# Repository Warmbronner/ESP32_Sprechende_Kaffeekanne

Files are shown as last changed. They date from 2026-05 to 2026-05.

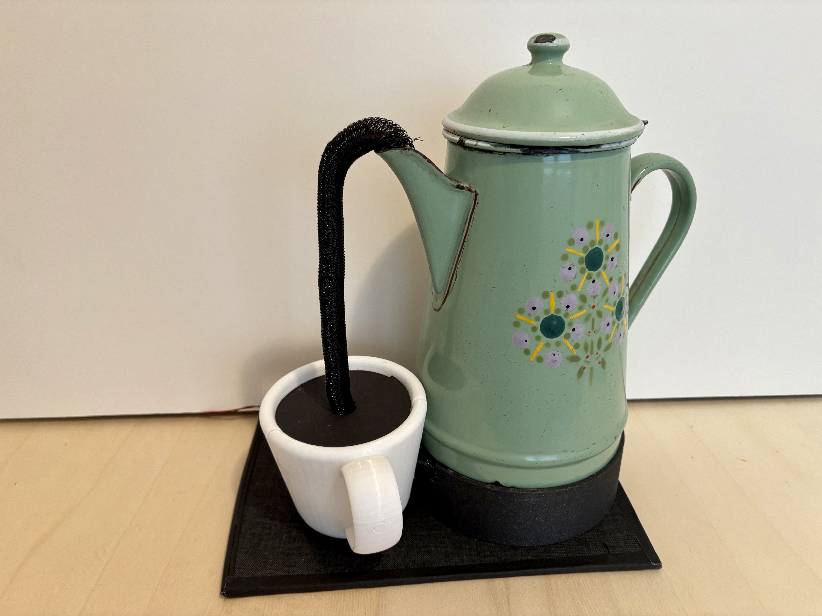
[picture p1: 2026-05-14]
Bilder/Abbildung3.jpeg

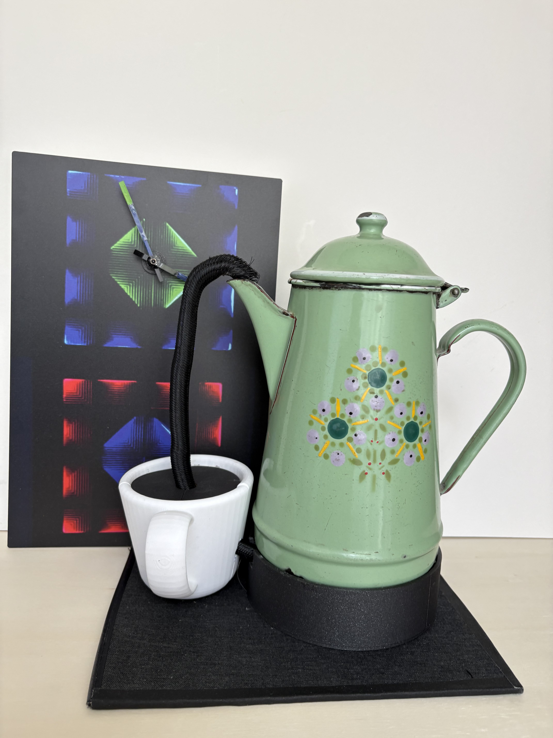
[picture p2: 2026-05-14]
Bilder/Abbildung7.jpeg

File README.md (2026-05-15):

# ESP32_Sprechende_Kaffeekanne
</> Markdown
# Sprechende Kaffeekanne
Sprechende_Kaffeekanne

Historische Kaffeekanne mit ESP32, MP3-Player, Servo und Neo Pixel als sprechende Uhr

Projektbeschreibung:
Eine historische Blech-Kaffeekanne lernt sprechen: Mit ESP32, MP3-Modul, Servo und etwas Fischertechnik entsteht eine ungewöhnliche Uhr mit Charakter.
•	Kombination aus Mechanik, Audio und Licht
•	Modulares Innenleben ohne Veränderungen an der Kanne
•	ESP32 mit WLAN-Zeitabgleich und synchronisierter Bewegung

Funktionen
Hardwareliste
•	ESP32 NodeMCU 32S
•	Servo M90 mit Metallgetriebe
•	MP3 MiniPlayer
•	Lautsprecher 8 Ohm, passend zum MP3 Player
•	Breadboard mini 2 x 3 cm
•	2 Widerstände 670 Ohm
•	1 Kondensator 0,01 F
•	NeoPixel-Streifen mit 4 LED’s
•	Jumperkabel
•	PLA Filament für Drei D Drucker
•	Klettband
>Kabelschlauch
•	3 Neodym Magnete 10 x 3 mm
•	4 Neodym Magnete 3 X 2 mm
•	Kabelbinder 
•	2 Gewindehülsen M3

Benötigte Werkzeuge:
•	3D-Drucker
•	Lötkolben
•	Seitenschneider
•	Heißklebepistole oder Sekundenkleber

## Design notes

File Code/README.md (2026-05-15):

Kaffeekanne_sprechend.ino ist der Code zur Steuerung des Projektes
KaffeeKanne_Test.ino ist der Code zum Testen der Funktionen und zur Abstimmung der Synchronisation MP3-dateien und Bewegung
Abgestimmt aus ESP32 NodeMCU-32S

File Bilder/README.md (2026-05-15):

Die Files, beginnend mit K3... sind für den Kasten 3 des Artikels vorgesehen.
Sollen in kleiner Bildgröße, etwa 3 x 3 cm dargestellt werden

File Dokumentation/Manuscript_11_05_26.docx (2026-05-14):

# Titel

Sprechende Kaffeekanne

# Vorspann

Eine historische Blech-Kaffeekanne lernt sprechen: Mit ESP32, MP3-Modul, Servo und etwas Fischertechnik entsteht eine ungewöhnliche Uhr mit Charakter.

# Kurzinfo

- Kombination aus Mechanik, Audio und Licht
- Modulares Innenleben ohne Veränderungen an der Kanne
- ESP32 mit WLAN-Zeitabgleich und synchronisierter Bewegung

Checkliste

Zeitaufwand: ein Wochenende

Kosten:
ca. 40 bis 60 Euro je nach vorhandenen Materialien und 3D-Druckmöglichkeiten, ohne Fischertechnik

Benötigte Kenntnisse:

- Grundlagen Arduino IDE
- Löten und Verdrahten
- Einfache Konstruktion mit 3D-Druck

Material

- ESP32 NodeMCU 32S
- Servo M90 mit Metallgetriebe
- MP3 MiniPlayer
- Lautsprecher 8 Ohm, passend zum MP3 Player
- Breadboard mini 2 x 3 cm
- 2 Widerstände 670 Ohm
- 1 Kondensator 0,01 F
- NeoPixel-Streifen mit 4 LED’s
- Jumperkabel
- PLA Filament für Drei D Drucker
- Klettband >Kabelschlauch
- 3 Neodym Magnete 10 x 3 mm
- 4 Neodym Magnete 3 X 2 mm
- Kabelbinder
- 2 Gewindehülsen M3

Benötigte Werkzeuge:

- 3D-Drucker
- Lötkolben
- Seitenschneider
- Heißklebepistole oder Sekundenkleber

# Einleitung

Es gibt Projekte, die sind praktisch. Und es gibt Projekte, die machen einfach Spaß – oft mit deutlich höherem Lernfaktor. Dieses hier gehört eindeutig zur zweiten Kategorie.

Auf einer Kommode in unserem Haushalt steht eine rund 100 Jahre alte, emaillierte Blech-Kaffeekanne. Eigentlich ein reines Dekostück – bis sich die Frage aufdrängte: Warum sollte sie nicht mehr können, als nur gut auszusehen?

Die Idee: Die Kanne soll sprechen. Genauer gesagt, sie soll regelmäßig die Uhrzeit ansagen – zur vollen oder halben Stunde. Eine etwas andere „sprechende Uhr“, die garantiert mehr Aufmerksamkeit bekommt als jedes Display.

Der besondere Reiz liegt im Detail: Der Deckel der Kanne ist beweglich und eignet sich perfekt, um als „Mund“ zu fungieren. Synchron zur Sprachausgabe soll er sich öffnen und schließen – eine mechanische Illusion von Sprache.

Von Anfang an war jedoch klar: Die Kanne selbst bleibt unangetastet. Keine Bohrungen, keine Klebespuren, keine bleibenden Veränderungen. Die gesamte Technik muss sich unsichtbar integrieren und rückstandslos wieder entfernen lassen – eine Herausforderung, die das Projekt erst richtig interessant macht.

Bildunterschrift Abbildung 1:
Die emaillierte Kaffeekanne dient als Basis des Projekts. Äußerlich bleibt sie vollständig unverändert.

# Konzept und Lösungsansatz

Damit aus der stummen Kanne ein erzählfreudiges Objekt wird, braucht es im Kern drei Dinge: Bewegung, Ton und ein wenig Inszenierung. Konkret heißt das: Der Deckel muss sich bewegen, eine Sprachausgabe muss abgespielt werden – und als visuelles Extra sorgt ein Licht im Inneren für den passenden „magischen“ Effekt. Gesteuert wird das Ganze von einem Mikrocontroller, der zusätzlich die aktuelle Uhrzeit ermittelt und verarbeitet.

Damit zerfällt das Projekt in vier zentrale Aufgaben:

- Mechanik für die Deckelbewegung
- Audioausgabe
- Beleuchtung
- Zeitbasis inklusive Steuerlogik

# Mechanik

Für die Bewegung des Deckels standen zunächst mehrere Ansätze zur Diskussion. Die erste Idee war ein klassischer Kurbeltrieb mit Pleuelstange. Funktioniert grundsätzlich gut, ist aber mechanisch vergleichsweise aufwendig.

Deutlich pragmatischer erwies sich der zweite Ansatz: Fischertechnik. Davon ist im Haushalt reichlich vorhanden, und die modularen Bauteile eignen sich perfekt für schnelle Prototypen. Der Antrieb erfolgt über einen Servo, da sich damit Positionen exakt anfahren lassen und der Nullpunkt zuverlässig reproduzierbar ist.

Zum Einsatz kam ein Servo M90 mit Metallgetriebe – robust genug für die Aufgabe und gut kontrollierbar. Die Kopplung zwischen Servo und Mechanik entstand aus einer improvisierten, aber effektiven Lösung: einer Scheibe mit Stellschraube, kombiniert mit den originalen Servoarmen. Zwei kleine Holzschrauben sorgen für die kraftschlüssige Verbindung.

Bildunterschrift Abbildung 2:
Die Mechanik kombiniert Fischertechnik-Bauteile mit einem kleinen Servo und einer selbstgebauten Kupplung.

Die Schubstange steht im eingebauten Zustand senkrecht und wird über eine Führung im Deckel stabilisiert. Der Servo selbst sitzt in einem 3D-gedruckten Gehäuse, das auf einem Fischertechnik-Element befestigt beziehungsweise verklebt ist.

# Audio

Für die Sprachausgabe fiel die Wahl schnell auf einen bewährten Klassiker: einen MP3-Mini-Player mit angeschlossenem Lautsprecher. Damit lässt sich die Audiowiedergabe unkompliziert ansteuern.

Aufwendiger als gedacht war hingegen die Erstellung der passenden Sprachdateien. Die Ansage muss nicht nur korrekt sein, sondern auch zeitlich zur Deckelbewegung passen. Erste Versuche mit Smartphone-Aufnahmen erwiesen sich als umständlich, vor allem wegen der nötigen Nachbearbeitung und Konvertierung.

Die Lösung brachte schließlich Audacity: aufnehmen, schneiden, anpassen – alles in einem Werkzeug. Damit ließ sich die Synchronisation zwischen Bewegung und Ton sauber umsetzen.

# Licht

Für den zusätzlichen Effekt sorgt eine dezente Innenbeleuchtung. Hier kommen adressierbare LEDs vom Typ NeoPixel zum Einsatz. Ein kurzer Streifen mit vier LEDs reicht völlig aus – tatsächlich werden nicht einmal alle benötigt.

Während der Sprachausgabe leuchtet das Kanneninnere leicht auf und verstärkt so den Eindruck, dass „innen etwas passiert“.

# Elektronik

Die ursprüngliche Idee war, die komplette Technik in der Kanne zu verstecken. In der Praxis scheiterte das schnell am verfügbaren Platz – und an der Wartbarkeit.

Gerade beim verwendeten ESP32 NodeMCU32S müssen zum Programmieren Taster zugänglich sein. Auch die SD-Karte des MP3-Moduls soll ohne Zerlegen erreichbar bleiben. Zudem lebt das Projekt davon, dass man später Dinge verändern und erweitern kann.

Die Lösung: Ein separater, abnehmbarer Unterbau. Darin sitzen:

- Mikrocontroller
- MP3-Modul
- Stromversorgung

Die Verbindung zur Kanne erfolgt über ein Kabelbündel, das durch die Tülle geführt wird. Optisch verschwindet es in einer schwarzen Ummantelung – getarnt als „Kaffeestrahl“. Der Übergang zum Unterbau wird zusätzlich durch eine dekorativ platzierte Tasse kaschiert.

Bildunterschrift Abbildung 3:
Der Unterbau enthält Elektronik und Stromversorgung. Die Verkabelung verschwindet im „Kaffeestrahl“.

# Innenleben

Das Innere der Kanne ist schwer zugänglich – also musste eine modulare Lösung her. Alle Komponenten im Inneren wurden zu einer kompakten Einheit zusammengefasst, die sich komplett einsetzen und wieder entnehmen lässt.

Die Form ergibt sich dabei fast von selbst: zylindrisch. Fündig wurde ich schließlich bei einer simplen Haushaltsdose für Flohsamenschalen, die zufällig perfekt in die Kanne passt.

Bildunterschrift Abbildung 4:
Das komplette Innenmodul sitzt in einer Kunststoffdose und lässt sich als Einheit entnehmen.

Im Inneren der Dose befinden sich die Mechanik, der Lautsprecher, die LEDs und die Führungselemente für die Schubstange.

Zum Herausnehmen dient ein stabiler Zwirnfaden, der unauffällig angebracht ist und bei Bedarf mit einem Haken herausgezogen werden kann.

# Zeitbasis

Herzstück der Steuerung ist ein ESP32, der gegenüber klassischen Arduino-Boards einen entscheidenden Vorteil bietet: WLAN. Damit lässt sich die Uhrzeit bequem über einen NTP-Server beziehen.

Der Programmcode basiert auf bestehenden Projekten und wurde schrittweise angepasst und erweitert. Besonders bei der Feinabstimmung – etwa beim Stromverbrauch, bei der Sommerzeitumstellung oder bei der Servoansteuerung – hat KI-Unterstützung überraschend effektiv geholfen.

# Bau und Umsetzung

Der praktische Aufbau beginnt – wie so oft – nicht mit Schrauben und Kleber, sondern mit einem provisorischen Versuchsaufbau auf dem Tisch. Alle Komponenten werden zunächst lose miteinander verbunden, um die grundsätzliche Funktion sicherzustellen, bevor Zeit in Mechanik und Gehäuse investiert wird.

Ausgangspunkt ist der Mikrocontroller, ein ESP32 NodeMCU-32S. Auf einem kleinen Breadboard werden Servo, MP3-Player, Lautsprecher und NeoPixel-Streifen angeschlossen. Widerstände und ein Kondensator stabilisieren die Signale und die Versorgung.

Bildunterschrift Abbildung 5:
Das Schaltschema zeigt die Verbindung von ESP32, MP3-Player, Servo, LEDs und Spannungsversorgung.

Bereits in dieser frühen Phase lohnt sich systematisches Testen. Zunächst wird der Servo isoliert angesteuert, um sicherzustellen, dass die Bewegung reproduzierbar und ruhig erfolgt. Anschließend folgt die Audioausgabe.

Genau hier zeigte sich im Projekt eine typische Stolperfalle: Der zunächst verwendete MP3-Player blieb komplett stumm. Weder Status-LED noch Audioausgabe reagierten. Erst der Austausch gegen ein alternatives Modul brachte Leben in die Schaltung.

Doch auch damit war das Problem noch nicht vollständig gelöst. Die Wiedergabe funktionierte zwar, aber nicht zuverlässig. Ursache war letztlich die Spannungsversorgung: Sobald alle Komponenten an einer gemeinsamen Quelle betrieben wurden, kam es zu Aussetzern.

Die Lösung bestand darin, die Versorgung aufzutrennen. Der MP3-Player erhielt eine eigene Spannungsquelle, während sich ESP32, Servo und LEDs eine zweite Versorgung teilen. Erst mit dieser Trennung lief das System stabil – eine Erfahrung, die man sich für ähnliche Projekte merken sollte.

Parallel zur Hardware entsteht der Programmcode. Statt bei null zu beginnen, bietet es sich an, vorhandene Routinen als Basis zu verwenden und schrittweise anzupassen. Zunächst werden einfache Testfunktionen implementiert: Servo bewegen, Audio abspielen, LEDs schalten. Im nächsten Schritt werden diese Funktionen zeitlich aufeinander abgestimmt.

Gerade die Synchronisation von Bewegung und Sprache erfordert etwas Geduld. Kleine Verzögerungen im Code und sauber geschnittene Audiodateien führen schließlich zum gewünschten Ergebnis. Unterstützung bei der Optimierung, etwa beim Stromverbrauch oder der Servo-Ansteuerung, lieferte ChatGPT.

Kasten 1:
Programmcode für den ESP32

Kasten 2:
Testcode zur Prüfung von Bewegung, Ton und Licht

Erst wenn Elektronik und Software zuverlässig funktionieren, lohnt sich der Übergang zur Mechanik.

Die Bewegungseinheit wird aus Fischertechnik-Elementen aufgebaut. Der Servo treibt über eine selbstgefertigte Kupplung eine kleine Kettenmechanik an. Auf der Kette sitzt ein Mitnehmer, der die Schubstange bewegt. Der Abstand der Zahnräder bestimmt dabei direkt den maximalen Hub – in diesem Fall etwa fünf Zentimeter.

Die Schubstange wird durch den Deckel geführt und dort stabilisiert. Um Reibung zu minimieren und ein Verkanten zu verhindern, wurde zunächst eine Rollenführung konstruiert.

Die Führung der Schubstange -siehe Kasten 3- stabilisiert den Deckel und reduziert störende Reibung.

Dieses Rollenelement enthält eine etwa vier Zentimeter lange Führungsstange, die durch ein zweites Loch im Deckel fixiert wird. Das gedruckte Teil zur Aufnahme der beiden Stangen ist ebenfalls im Kasten mit den 3D-gedruckten Bauteilen dargestellt.

Damit Madenschrauben zur Fixierung der beiden Stangen untergebracht werden können, sind die Sackbohrungen mit Gewindehülsen M3 versehen. Die Gewindehülsen werden mit einem Lötkolben auf etwa 200 Grad Celsius erwärmt und anschließend eingedrückt.

Die Konstruktion funktioniert zuverlässig, ist aber vergleichsweise aufwendig. In der Praxis hätte auch eine einfache Kunststoffkappe am Ende der Schubstange denselben Zweck erfüllt.

Parallel dazu entsteht das Innenmodul. Die gewählte Dose wird seitlich geöffnet, um Zugang zur Mechanik zu schaffen.

Auf Boden und Mechanik werden Klettstreifen angebracht – eine einfache, aber äußerst praktische Lösung, um Komponenten später wieder lösen zu können.

Um die Dose in der Kanne zu zentrieren, entstand zusätzlich ein gedruckter Distanzring, der lose auf dem Kannenboden liegt.

Der Deckel der Dose übernimmt mehrere Funktionen gleichzeitig: Er trägt die Führung der Schubstange, den Lautsprecher sowie den LED-Streifen. Die Verkabelung wird durch den Deckel in die Dose und anschließend nach außen geführt.

Vor dem endgültigen Einbau folgt ein vollständiger Funktionstest:

- Bewegt sich der Deckel sauber?
- Passt die Synchronisation?
- Funktionieren Licht und Ton zuverlässig?

Erst wenn alle Fragen mit „Ja“ beantwortet sind, wird das Modul vorsichtig in die Kanne eingeschoben und am Boden fixiert. Eine einfache Fadenschlaufe ermöglicht es, das Modul später wieder herauszuziehen – ein kleines Detail mit großem praktischem Nutzen.

Der Unterbau entsteht anschließend im 3D-Druck. Er besteht aus zwei Teilen – Rahmen und Boden –, die später miteinander verklebt werden.

Bildunterschrift Abbildung 6:
Die gedruckten Teile des Unterbaus nehmen Elektronik und Stromversorgung auf.

Darin finden ESP32, MP3-Player, Stromanschlüsse und Breadboard ihren Platz.

Für die Befestigung an der Kanne kommen Neodym-Magnete zum Einsatz. Da die Kanne aus Blech besteht, hält diese Lösung überraschend zuverlässig – und bleibt vollständig reversibel.

Wichtig bei der Konstruktion: Die Bedienelemente des ESP32 müssen zugänglich bleiben. Entsprechend wurden im Boden Öffnungen für Boot- und Reset-Taster vorgesehen.

Zum Abschluss werden alle Kabel zusammengeführt und durch die Tülle der Kanne nach unten geleitet. Ein schwarzer Kabelschlauch bündelt die Leitungen und tarnt sie gleichzeitig als „Kaffeestrahl“.

Die zusätzlich platzierte, zweiteilige Kaffeetasse verdeckt den Übergang zum Unterbau und rundet die Illusion ab. Auch den Zusammenhalt der beiden Teile übernehmen kleine Neodym-Magnete.

Kasten 3:
Übersicht der 3D-gedruckten Bauteile

# Fazit

Technisch ist das Projekt überschaubar – aber voller kleiner Herausforderungen.

Die wichtigsten Erkenntnisse:

- Nicht jedes Elektronikmodul hält, was es verspricht
- MP3-Player reagieren empfindlich auf die Stromversorgung
- Mechanik muss nicht nur funktionieren, sondern auch leise sein
- Modulare Bauweise spart später viel Aufwand
- Baukastensysteme wie Fischertechnik sind überraschend vielseitig

Besonders hilfreich war der Einsatz von KI-Tools wie ChatGPT – sowohl bei der Softwareentwicklung als auch bei der Fehlersuche.

Am Ende steht ein Projekt, das objektiv betrachtet wenig Nutzen hat – aber genau deshalb überzeugt. Denn manchmal ist es eben die nutzlose Idee, die am meisten Spaß macht.

Der Nutzwert lässt sich problemlos erhöhen: Die Zeitansage könnte beispielsweise viertel- oder halbstündlich erfolgen. Ebenso wäre eine Kombination mit einer klassischen Uhr denkbar. Dann würde aus der sprechenden Kaffeekanne sogar ein vollständiges Zeit-Informationssystem.

Abbildung 7 Kaffeekanne ergänzt durch analoge Uhr

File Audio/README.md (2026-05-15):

Die MP3-Dateien müssen im Verzeichnis /mp3
des DFPlayers, also der SD-Karte liegen.

Benennung:
0001.mp3 bis 0012.mp3

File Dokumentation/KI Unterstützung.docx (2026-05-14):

## Kasten 4: KI-Unterstützung sinnvoll nutzen

KI-Werkzeuge wie ChatGPT können bei Elektronik- und Maker-Projekten erstaunlich hilfreich sein. Gerade bei komplexeren Projekten mit Mechanik, Elektronik, Programmcode und Dokumentation spart die Unterstützung durch KI oft viel Zeit.

Auch bei der Entwicklung der sprechenden Kaffeekanne kam KI an mehreren Stellen zum Einsatz:

- beim Erstellen und Optimieren des ESP32-Programmcodes,
- bei der Fehlersuche rund um den MP3-Player,
- bei der Sommer-/Winterzeit-Umschaltung,
- bei der Strukturierung des GitHub-Repositorys,
- sowie bei der Ausarbeitung und Redaktion dieses Artikels.

Damit KI jedoch brauchbare Ergebnisse liefert, kommt es stark darauf an, wie Fragen gestellt werden. Unscharfe oder sehr allgemeine Formulierungen führen oft zu unpräzisen Antworten. Besser funktioniert ein schrittweises Vorgehen.

Hilfreich sind insbesondere folgende Regeln:

- Kurze und klare Sätze formulieren
- Möglichst nur ein Problem gleichzeitig behandeln
- Das gewünschte Ziel eindeutig beschreiben
- Verwendete Hardware möglichst genau angeben
- Fehlermeldungen vollständig übernehmen
- Bei Problemen auch Fotos oder Schaltpläne bereitstellen
- Schrittweise nachfragen statt alles auf einmal lösen wollen

Besonders wichtig: Die KI kennt den tatsächlichen Aufbau nicht. Deshalb sollte man möglichst viele Randbedingungen nennen, beispielsweise:

- verwendeter Mikrocontroller,
- Spannungsversorgung,
- Bibliotheken,
- Sensoren oder Module,
- sowie das gewünschte Verhalten.

Statt:

„Mein MP3-Player funktioniert nicht“

liefert beispielsweise eine präzisere Beschreibung deutlich bessere Ergebnisse:

„DFPlayer Mini an ESP32. LED am Modul leuchtet nicht. Versorgung 5 Volt. Software startet ohne Fehlermeldung.“

Gerade bei Programmcode empfiehlt sich außerdem ein iteratives Vorgehen: zunächst kleine Teilfunktionen testen, dann schrittweise erweitern. Auch dabei kann KI sehr gut unterstützen.

Trotz aller Möglichkeiten bleibt jedoch wichtig:
KI ersetzt weder eigenes Nachdenken noch praktische Tests. Besonders bei Elektronikprojekten müssen Vorschläge immer kritisch geprüft werden. Die besten Ergebnisse entstehen meist dann, wenn menschliche Erfahrung und KI-Unterstützung zusammenarbeiten.

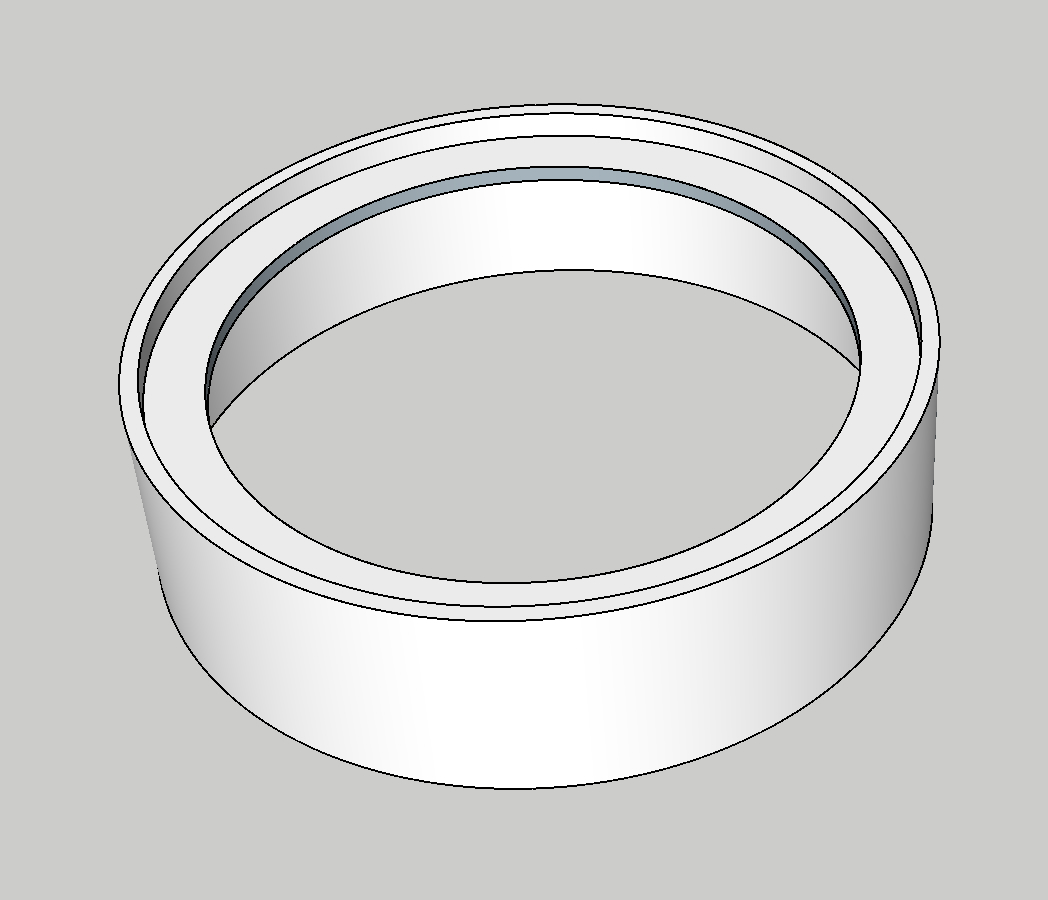
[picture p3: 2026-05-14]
Bilder/K3_Unterbau.jpg

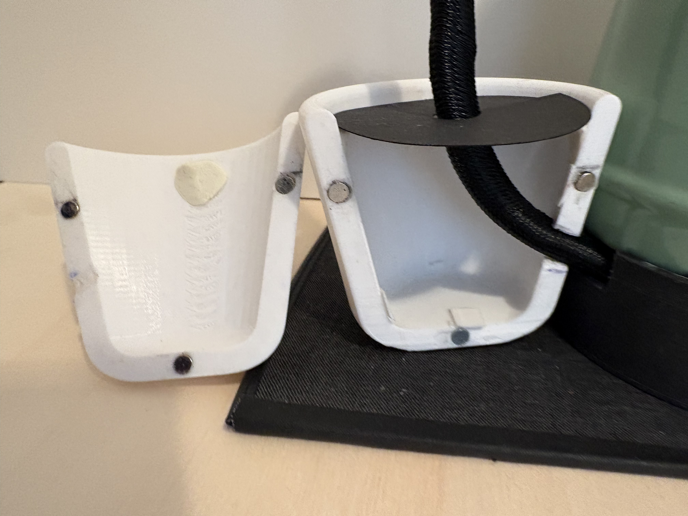
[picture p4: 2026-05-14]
Bilder/K3Tasse_geteilt.jpeg

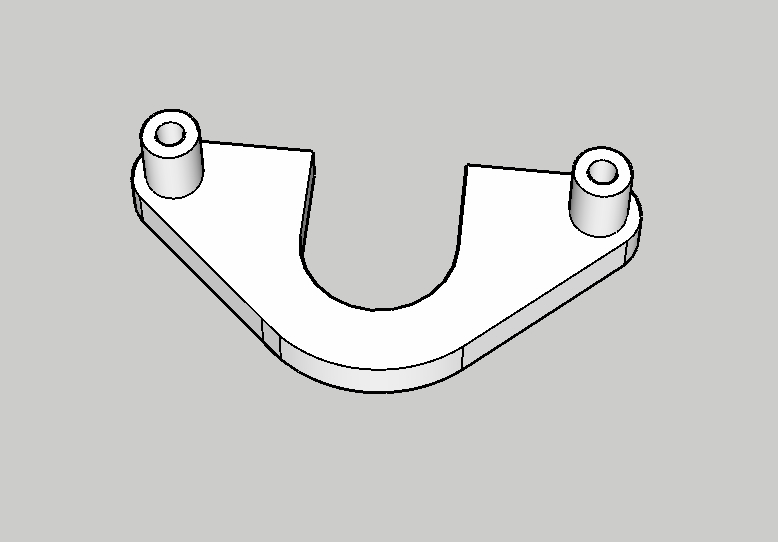
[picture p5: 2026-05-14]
Bilder/K3_Fixierung_Führung.jpg

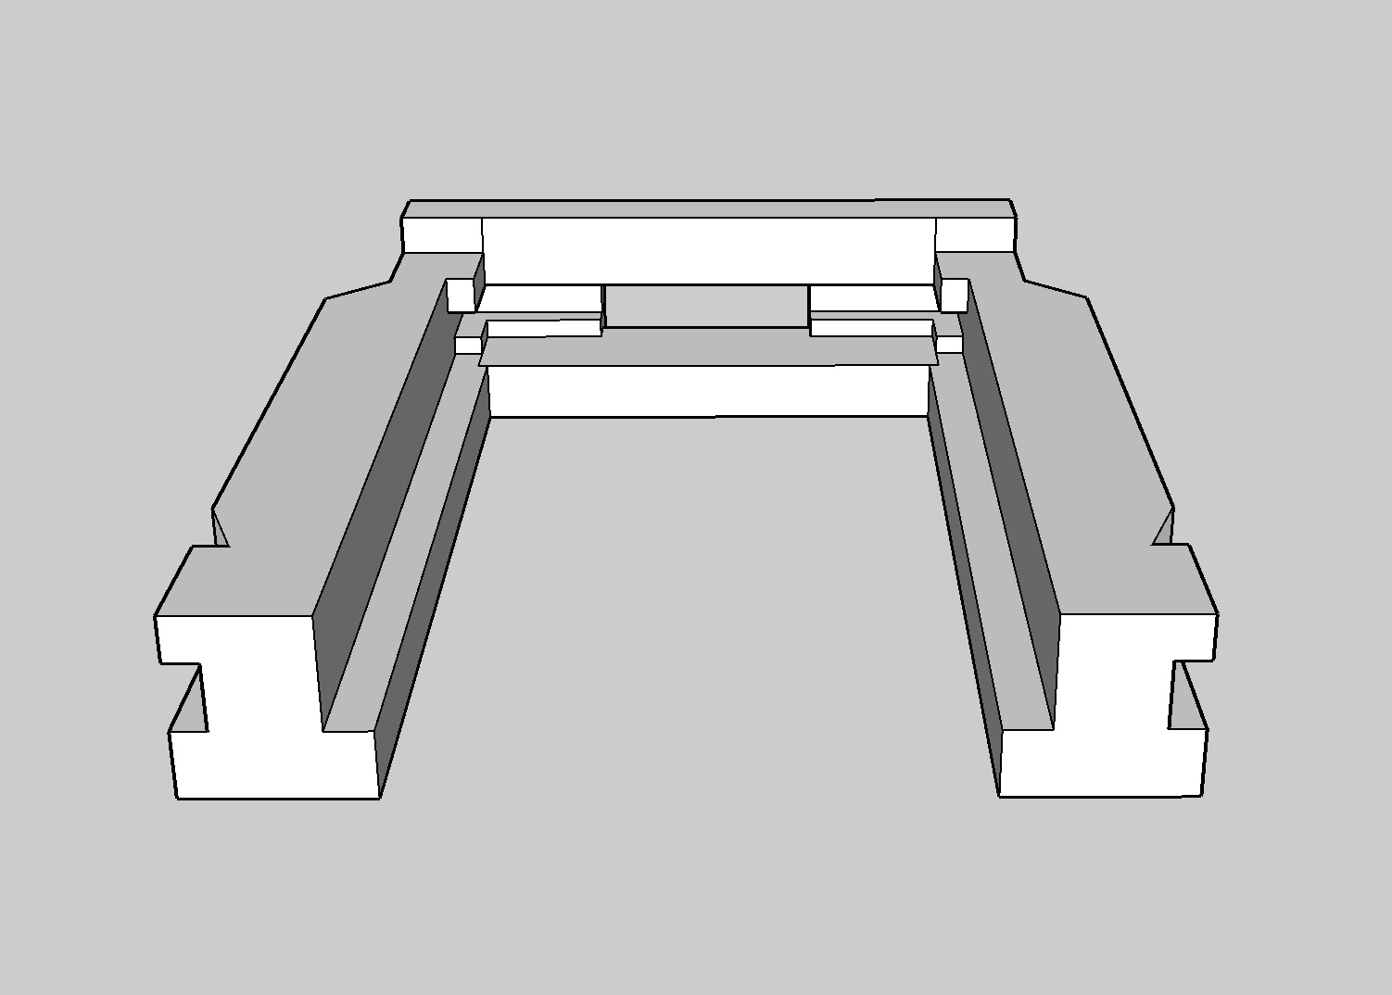
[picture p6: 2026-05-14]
Bilder/K3_ESP_Halter_vorne.jpg

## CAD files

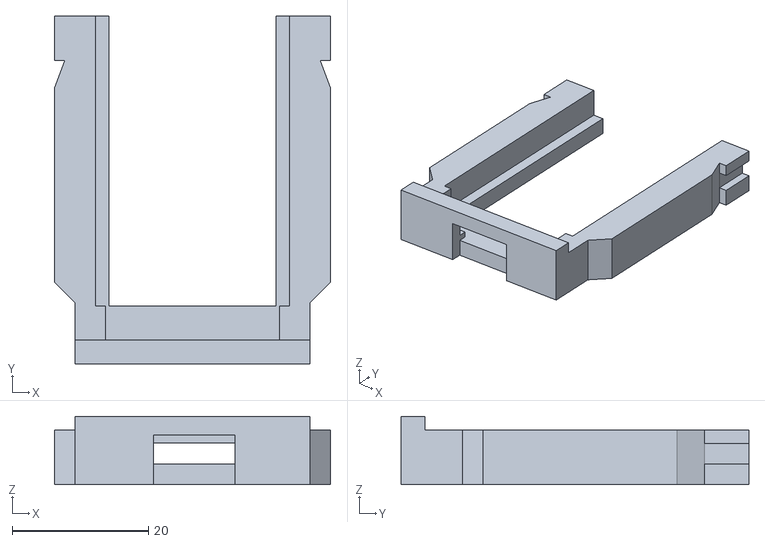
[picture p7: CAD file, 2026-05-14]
STL/ESP_Halter_vorne.stl
40.5 x 51.0 x 10.0

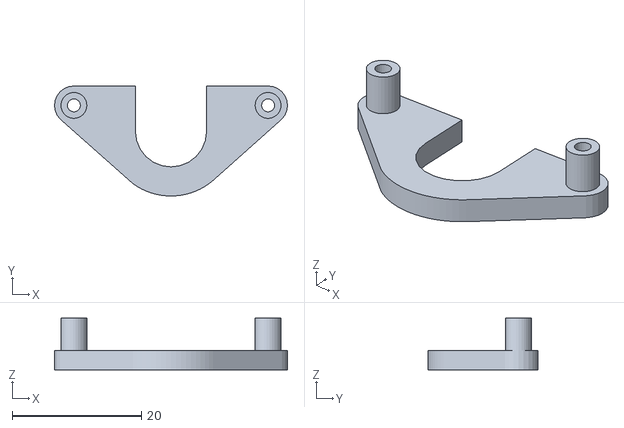
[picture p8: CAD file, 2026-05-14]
STL/Fixierung_Führung.stl
36.0 x 17.0 x 8.00

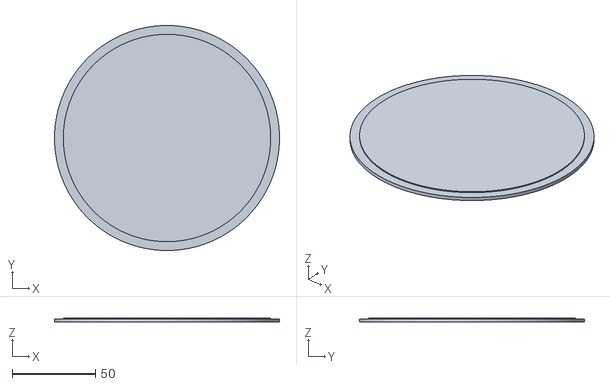
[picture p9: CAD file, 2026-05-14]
STL/Boden_Unterbau.stl
135.0 x 135.0 x 2.60

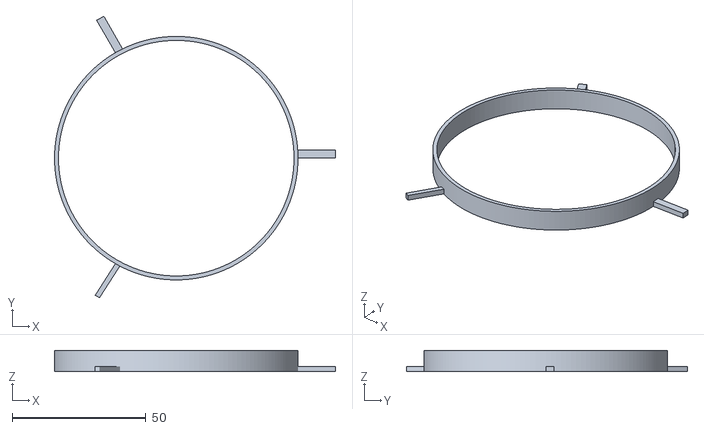
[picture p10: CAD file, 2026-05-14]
STL/Distanz_unten.stl
105.0 x 105.2 x 8.00

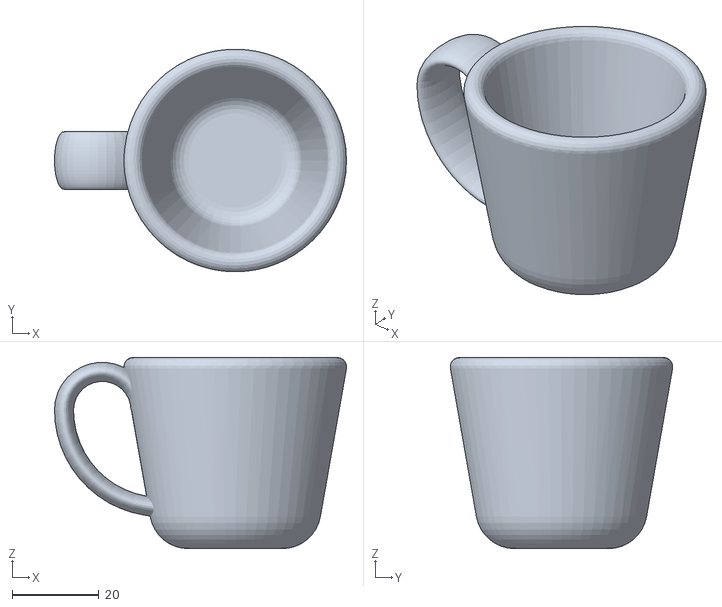
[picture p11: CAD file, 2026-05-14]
STL/Tasse.stl
67.2 x 51.2 x 44.0

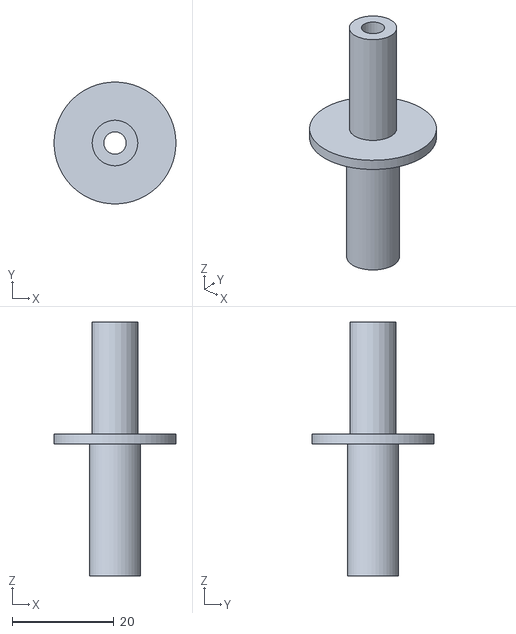
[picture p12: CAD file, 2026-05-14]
STL/Führung.stl
24.0 x 24.0 x 50.0

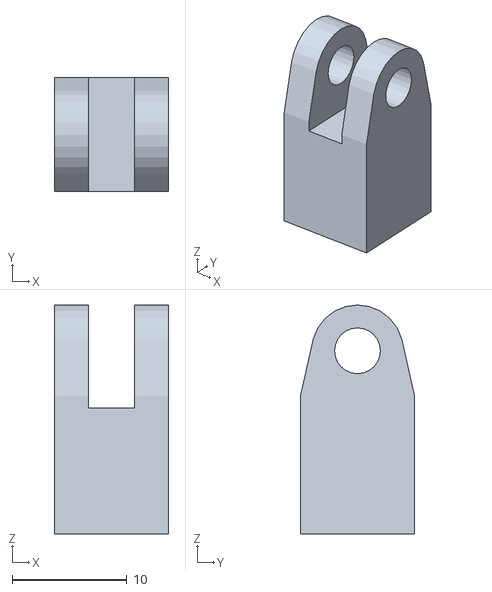
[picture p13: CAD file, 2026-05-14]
STL/Rollenhalter.stl
10.00 x 10.00 x 20.0

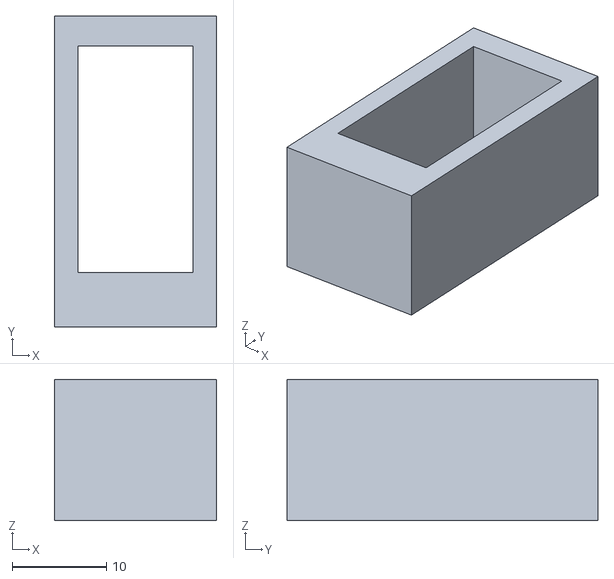
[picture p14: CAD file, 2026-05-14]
STL/Servo_Haus.stl
17.2 x 33.0 x 15.0

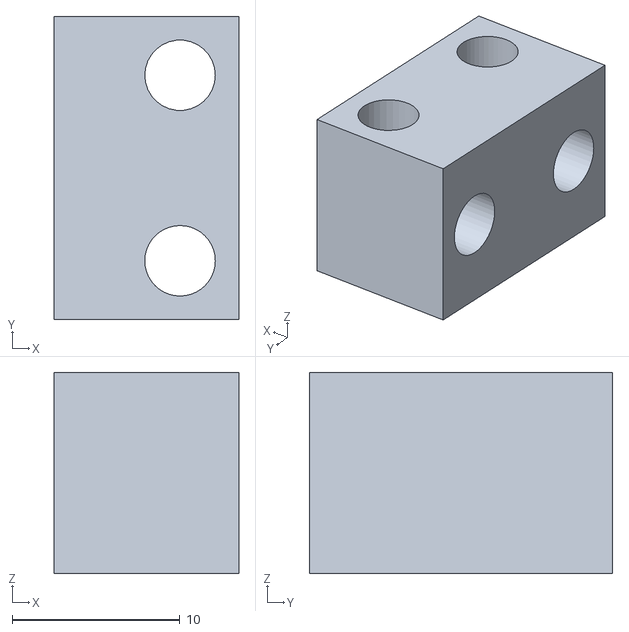
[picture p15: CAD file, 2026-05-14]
STL/Halter_Stangen.stl
11.0 x 18.1 x 12.0

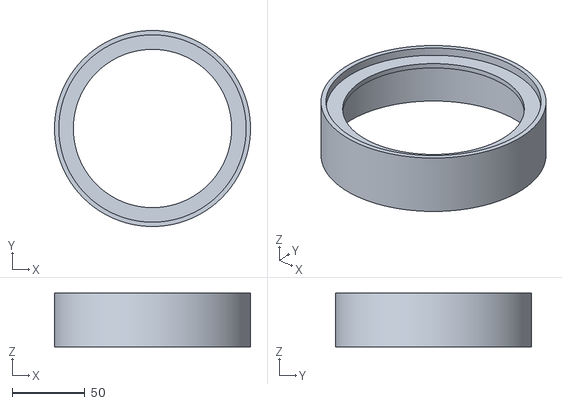
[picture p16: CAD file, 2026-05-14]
STL/Unterbau.stl
135.0 x 135.0 x 37.0

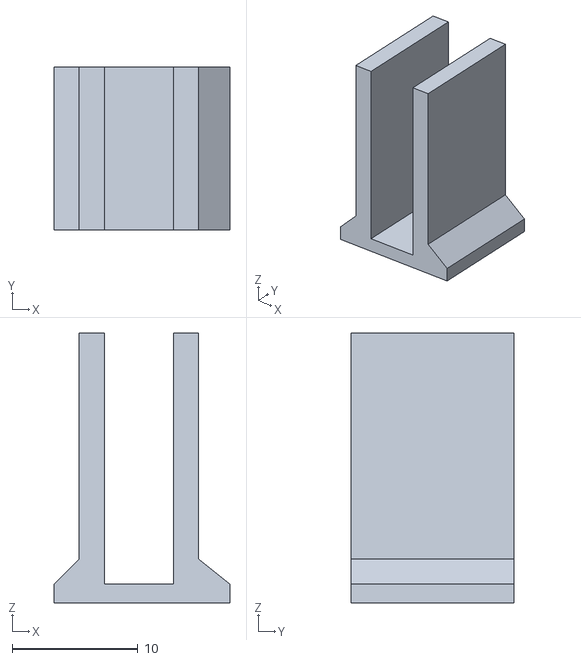
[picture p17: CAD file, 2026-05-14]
STL/Halter_MP3Player.stl
14.0 x 13.0 x 21.5

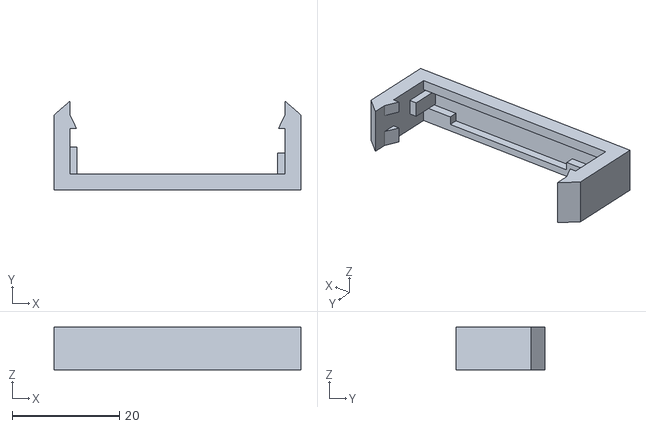
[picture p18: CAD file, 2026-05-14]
STL/ESP_Halter_hinten.stl
46.1 x 16.6 x 8.00

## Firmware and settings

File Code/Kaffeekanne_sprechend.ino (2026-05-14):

#include <WiFi.h>
#include <NTPClient.h>
#include <WiFiUdp.h>
#include <Adafruit_NeoPixel.h>
#include <ESP32Servo.h>
#include <DFRobotDFPlayerMini.h>

// =========================================
// WLAN
// =========================================
const char* ssid     = "Garten_3";
const char* password = "Schlaegel#1910";

// =========================================
// NTP
// =========================================
WiFiUDP ntpUDP;
NTPClient timeClient(ntpUDP, "pool.ntp.org", 3600); // Start mit Winterzeit

// =========================================
// Pins
// =========================================
#define LED_PIN     2
#define NUM_LEDS    3
#define SERVO_PIN   5

#define DF_RX_PIN   16
#define DF_TX_PIN   17

// =========================================
// Servo Einstellungen
// =========================================
#define SERVO_MIN 12
#define SERVO_MAX 120

int servoPause = 600;

// =========================================
// Objekte
// =========================================
Adafruit_NeoPixel strip(NUM_LEDS, LED_PIN, NEO_GRB + NEO_KHZ800);
Servo movementServo;

HardwareSerial dfSerial(1);
DFRobotDFPlayerMini dfPlayer;

int lastRunHour = -1;
int lastOffset = 3600;

// =========================================
// Sommerzeit (EU)
// =========================================
bool isDST(int year, int month, int day, int hour)
{
  if(month < 3 || month > 10) return false;
  if(month > 3 && month < 10) return true;

  int lastSunday = day - ((day + 6) % 7);

  if(month == 3)
    return lastSunday >= 25 && hour >= 2;

  if(month == 10)
    return !(lastSunday >= 25 && hour >= 3);

  return false;
}

// =========================================
// NeoPixel
// =========================================
void setNeoPixel(bool on)
{
  if (on)
  {
    for(int i=0;i<NUM_LEDS;i++)
      strip.setPixelColor(i, strip.Color(0,200,255));
  }
  else
  {
    strip.clear();
  }
  strip.show();
}

// =========================================
// Servo Bewegung
// =========================================
void servoMovement()
{
  movementServo.attach(SERVO_PIN);
  movementServo.setPeriodHertz(50);

  for(int i=0;i<2;i++)
  {
    movementServo.write(SERVO_MAX);
    delay(1000);

    delay(servoPause);

    movementServo.write(SERVO_MIN);
    delay(400);
  }

  movementServo.detach();
}

// =========================================
// Stundenroutine
// =========================================
void hourlyRoutine(int hour)
{
  Serial.printf(">>> Spiele Stunde: %02d\n", hour);

  setNeoPixel(true);

  dfPlayer.playMp3Folder(hour);

  delay(200);

  servoMovement();

  delay(5000);

  setNeoPixel(false);

  Serial.println(">>> Fertig");
}

// =========================================
// Setup
// =========================================
void setup()
{
  Serial.begin(115200);
  delay(1000);

  strip.begin();
  strip.clear();
  strip.show();

  movementServo.attach(SERVO_PIN);
  movementServo.write(SERVO_MIN);
  delay(300);
  movementServo.detach();

  Serial.print("Verbinde WLAN");

  WiFi.begin(ssid,password);

  while(WiFi.status()!=WL_CONNECTED)
  {
    delay(500);
    Serial.print(".");
  }

  Serial.println("\nWLAN verbunden");

  timeClient.begin();

  dfSerial.begin(9600,SERIAL_8N1,DF_RX_PIN,DF_TX_PIN);

  if(!dfPlayer.begin(dfSerial))
  {
    Serial.println("DFPlayer Fehler!");
    while(true);
  }

  dfPlayer.volume(25);

  Serial.println("System bereit");
}

// =========================================
// Loop
// =========================================
void loop()
{
  timeClient.update();

  // aktuelle Zeit holen
  int hour24 = timeClient.getHours();
  int minute = timeClient.getMinutes();
  int second = timeClient.getSeconds();

  // Datum holen (für DST)
  time_t epochTime = timeClient.getEpochTime();
  struct tm *ptm = gmtime((time_t *)&epochTime);

  int year  = ptm->tm_year + 1900;
  int month = ptm->tm_mon + 1;
  int day   = ptm->tm_mday;

  // Sommer-/Winterzeit bestimmen
  int offset = 3600;
  if(isDST(year, month, day, hour24))
    offset = 7200;

  if(offset != lastOffset)
  {
    timeClient.setTimeOffset(offset);
    lastOffset = offset;

    Serial.printf("Offset geändert: %d Sekunden\n", offset);
  }

  // 12h Format
  int hour12 = hour24 % 12;
  if(hour12 == 0) hour12 = 12;

  Serial.printf("Zeit %02d:%02d:%02d | Ansage: %02d\n",
                hour24, minute, second, hour12);

  // Trigger zur vollen Stunde
  if(minute == 0 && second < 5 && hour12 != lastRunHour)
  {
    lastRunHour = hour12;
    hourlyRoutine(hour12);
  }

  delay(500);
}
